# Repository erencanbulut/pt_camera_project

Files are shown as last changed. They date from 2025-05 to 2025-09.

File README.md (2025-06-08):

# PT Camera Project

The project aims to provide researchers with a low-cost, open-source pan-tilt (PT) camera system for use in various robotic applications, such as autonomous unmanned aerial vehicle (UAV) landings on unmanned surface vehicles (USVs).

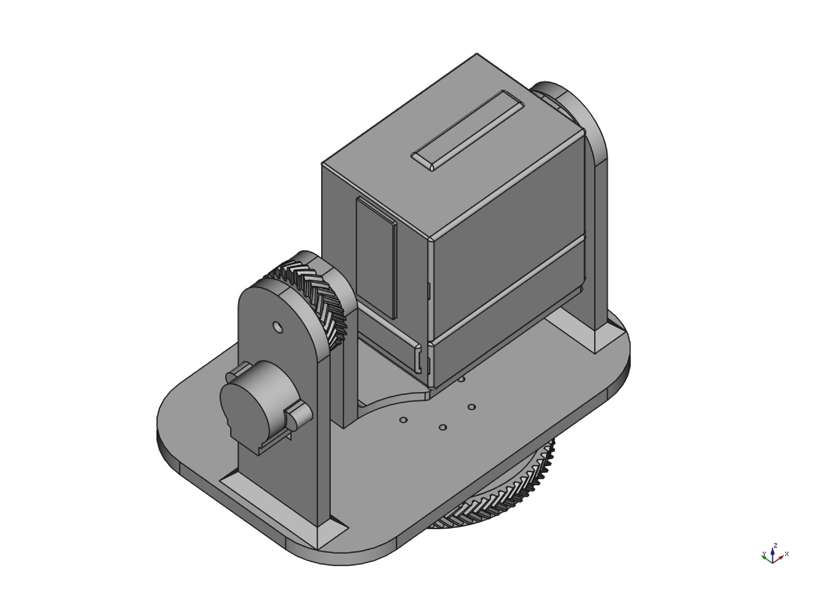
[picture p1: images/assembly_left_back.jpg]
PT Camera Assembly


# BoM
| Item Nr. | Product | Price (€) | Pieces | Link |
|---|---|---|---|---|
| 1 | Raspberry Pi 4 Model B 4 GB RAM | 48.99 | 1 | [Link](https://mou.sr/43gMQWg) |
| 2 | Raspberry Pi 16 MM Lens | 59.00 | 1 | [Link](https://buyzero.de/en/products/16mm-teleobjektiv-fur-hq-kamera-16mm-telephoto-lens-for-hq-camera) |
| 3 | Raspberry Pi 12 MP HQ Camera | 52.00 | 1 | [Link](https://www.digikey.de/short/p40hw30b) |
| 4 | Micro-SDHC 32 GB, 120 MB/s | 5.70 | 1 | [Link](https://www.berrybase.de/sandisk-ultra-microsdhc-a1-120mb-s-class-10-speicherkarte-adapter-32gb) |
| 5 | RB-Moto2 with 28byj-48 Stepper Motors | 12.52 | 3 | [Link](https://www.reichelt.com/de/en/shop/product/raspberry_pi_-_motor_control_incl_stepper_motors_uln2803apg-176628) |
| 6 | Intenso 7313535 Powerbank 10,000 mAh | 14.49 | 1 | [Link](https://amzn.eu/d/eHD4hbB) |
| 7 | Prusament PETG Filament (1 kg) | 29.99 | 1 | [Link](https://www.prusa3d.com/de/produkt/prusament-petg-carmine-red-transparent-1kg/) |
| 8 | Charge Cable (C to C) | 13.84 | 1 | [Link](https://de.rs-online.com/web/p/usb-kabel/2566994?gb=bb) |
| 9 | SKF 623-2Z Deep Groove Ball Bearing  | 4.82 | 2 | [Link](https://motionparts.de/products/623-2z-skf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) |
| 10 | M3 Cylinder Screw | 3.50 | 25 | [Link](https://rc-schrauben.de/Zylinderkopfschraube-DIN-912-M3-x-12-Edelstahl-A2) |
| 11 | M3 Hex Nuts | 0.43 | 25 | [Link](https://de.farnell.com/en-DE/tr-fastenings/m3-hfst-z100/nut-full-steel-bzp-m3-pk100/dp/1419447) |
| 12 | M3 Washer | 0.43 | 25 | [Link](https://de.farnell.com/en-DE/duratool/wash3/washer-steel-m3-pk100/dp/1377496) |
| 13 | M2 Cylinder Screws | 1.60 | 8 | [Link](https://rc-schrauben.de/Zylinderkopfschraube-DIN-912-M2-x-8-Stahl-129) |
| 14 | M2 Hex Nuts | 1.08 | 4 | [Link](https://rc-schrauben.de/Hexagon-Nut-DIN-934-M2-Stainless-steel) |
| | **Total Price** | **248.11**| | |

# Test and Performance Analyses

This part summarizes the experimental results and performance analyses.

---

## Pan and Tilt Performance

### Maximum Angular Speed

| Axis | Theoretical Speed | Measured Avg. Speed | Notes |
|---|---|---|---|
| Pan  | 31.39°/s | ~28.83°/s | Small loss (~8%) |
| Tilt | 48.83°/s | ~38.69°/s | Greater loss (~20%) |

- **Cause**: Mechanical design and weight.
- **Solution**: Higher torque motors, lighter construction, step timing optimization.

### Maximum Angular Range

| Axis | Max Angle (Up/Down) |
|---|---|
| Pan  | ±360° |
| Tilt | -95° to +30° |

- **Limitation**: Weight and cable strain.

### Combined Motion Execution Time

- **Expected**: 6.34 s
- **Measured**: 7.78 s (~22.7% longer)
- **Reason**: Acceleration delay and stepper lag during combined pan/tilt motion

---

## Object Detection – Free-Fall (Vertical)

| Distance | Detection Rate |
|---|---|
| 0.5 m | 17.64% |
| 1 m | 23.74% |
| 2 m | 48.61% |

- **Test**: HSV-based tracking of a fast-dropping yellow ball.
- **Simulation**: UAV speed during descent (5 m/s).
- **Insight**: Detection improves with distance due to better motion visibility.
- **Needs**:
  - Faster frame rate
  - Reduced exposure time
  - Predictive tracking (Kalman)
  - Real-time lightweight AI models

---

## Object Detection – Oscillation (Lateral)

| Distance | Detection Rate |
|---|---|
| 0.5 m | 25.05% |
| 1 m | 59.05% |
| 2 m | 96.41% |

- **Test**: HSV-based tracking of a laterally oscillating yellow ball.
- **Simulation**: UAV lateral drift (300°/s).
- **Finding**: Excellent performance for lateral motion at long range (2 m).

---

## Latency Analysis

- **Mean latency**: ~93.75 ms
- **Range**: 83.3 – 104.2 ms
- **Impact**: 
  - Camera preview latency measured using 240 fps slow-motion recording.
  - Frame difference used to calculate latency: Latency (ms) = (Δframes / 240) x 1000

**Conclusion**: Sufficient for real-time UAV tracking (<150 ms acceptable limit)

---

## Power Consumption

- 10,000 mAh battery yields **8+ hours** runtime during full tracking operation.
- ~5× better energy efficiency than commercial PTZ systems.
- Modular design allows for easy battery replacement or upgrades.

---

## Maritime Suitability (Sea State)

| Sea State | Status |
|---|---|
| SS 0–3 | Stable tracking |
| SS 4 | Reduced performance |
| SS 5+ | Not suitable |

---

## Commercial Comparison

### Advantages
- Modular and open-source
- Low-cost and long battery life
- Reliable object tracking (esp. lateral)
- Weather-resistant housing

### Limitations
- Slower tracking speeds
- Higher weight → suited for static or vehicle-mounted use

---

## Recommended Improvements

- Upgrade to stronger, faster stepper motors
- Redesign cable routing for better tilt range
- Optimize mechanical parts for weight reduction
- Use Jetson Nano/Xavier for real-time AI-based tracking
- Add stereo vision for 3D detection and UAV depth estimation
- Field test in maritime environments

---

📁 GitHub Repository: [erencanbulut/pt_camera_project](https://github.com/erencanbulut/pt_camera_project)

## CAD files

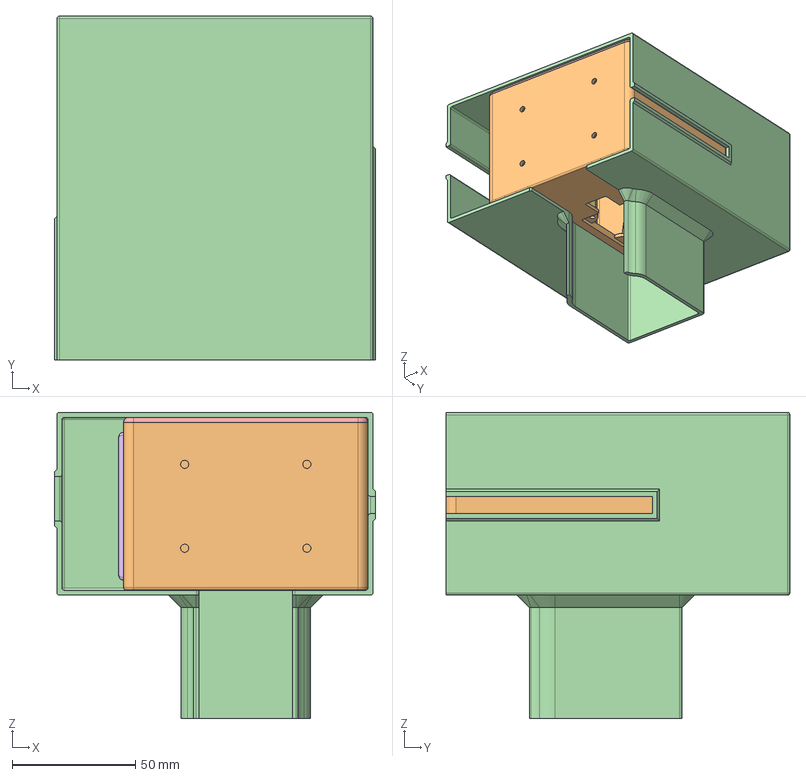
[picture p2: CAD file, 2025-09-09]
step_files/rpi_hq_cam_housing_v13.step
130.1 x 139.3 x 124.1 mm
FrontLid
CameraHousing
TopPortsLid
Case
BatterySlotLid
BatteryPortsLid
RPiPortsLid

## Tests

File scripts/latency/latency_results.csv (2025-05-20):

Real Frame | Preview Frame | ΔFrames | Latency (ms)
frame_6.png | frame_28.png | 22 | 91.67
frame_11.png | frame_32.png | 21 | 87.5
frame_15.png | frame_38.png | 23 | 95.83
frame_26.png | frame_46.png | 20 | 83.33
frame_29.png | frame_51.png | 22 | 91.67
frame_39.png | frame_60.png | 21 | 87.5
frame_46.png | frame_68.png | 22 | 91.67
frame_53.png | frame_75.png | 22 | 91.67
frame_60.png | frame_85.png | 25 | 104.17
frame_68.png | frame_90.png | 22 | 91.67
frame_76.png | frame_97.png | 21 | 87.5
frame_81.png | frame_106.png | 25 | 104.17
frame_90.png | frame_111.png | 21 | 87.5
frame_97.png | frame_119.png | 22 | 91.67
frame_104.png | frame_128.png | 24 | 100.0
frame_110.png | frame_133.png | 23 | 95.83
frame_119.png | frame_142.png | 23 | 95.83
frame_124.png | frame_149.png | 25 | 104.17
frame_133.png | frame_156.png | 23 | 95.83
frame_140.png | frame_161.png | 21 | 87.5
frame_145.png | frame_170.png | 25 | 104.17
frame_153.png | frame_174.png | 21 | 87.5
frame_160.png | frame_182.png | 22 | 91.67
frame_167.png | frame_190.png | 23 | 95.83
frame_174.png | frame_198.png | 24 | 100.0
frame_181.png | frame_202.png | 21 | 87.5
frame_188.png | frame_212.png | 24 | 100.0
frame_196.png | frame_216.png | 20 | 83.33
frame_202.png | frame_227.png | 25 | 104.17
frame_216.png | frame_238.png | 22 | 91.67

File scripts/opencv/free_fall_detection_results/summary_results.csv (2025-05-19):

Distance | Total Frames | Detected Frames | Detection Rate (%)
0.5 | 19 | 3 | 15.79
0.5 | 19 | 3 | 15.79
0.5 | 20 | 3 | 15.0
0.5 | 19 | 4 | 21.05
0.5 | 19 | 3 | 15.79
0.5 | 18 | 3 | 16.67
0.5 | 18 | 5 | 27.78
0.5 | 15 | 2 | 13.33
0.5 | 18 | 2 | 11.11
0.5 | 13 | 3 | 23.08
1 | 17 | 4 | 23.53
1 | 16 | 3 | 18.75
1 | 16 | 5 | 31.25
1 | 12 | 3 | 25.0
1 | 17 | 4 | 23.53
1 | 15 | 3 | 20.0
1 | 18 | 4 | 22.22
1 | 17 | 4 | 23.53
1 | 17 | 4 | 23.53
1 | 17 | 4 | 23.53
2 | 17 | 8 | 47.06
2 | 17 | 8 | 47.06
2 | 17 | 8 | 47.06
2 | 18 | 9 | 50.0
2 | 13 | 6 | 46.15
2 | 17 | 8 | 47.06
2 | 16 | 8 | 50.0
2 | 15 | 7 | 46.67
2 | 18 | 9 | 50.0
2 | 16 | 8 | 50.0

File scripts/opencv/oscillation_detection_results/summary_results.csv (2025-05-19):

Distance (m) | Total Frames | Detected Frames | Detection Rate (%)
0.5 | 637 | 150 | 23.55
0.5 | 637 | 150 | 23.55
0.5 | 640 | 163 | 25.47
0.5 | 639 | 180 | 28.17
0.5 | 639 | 159 | 24.88
0.5 | 647 | 160 | 24.73
0.5 | 638 | 153 | 23.98
0.5 | 523 | 123 | 23.52
0.5 | 636 | 159 | 25.0
0.5 | 527 | 135 | 25.62
1 | 637 | 393 | 61.7
1 | 642 | 382 | 59.5
1 | 635 | 320 | 50.39
1 | 627 | 425 | 67.78
1 | 640 | 374 | 58.44
1 | 536 | 337 | 62.87
1 | 633 | 368 | 58.14
1 | 632 | 375 | 59.34
1 | 632 | 321 | 50.79
1 | 629 | 387 | 61.53
2 | 591 | 576 | 97.46
2 | 607 | 587 | 96.71
2 | 601 | 581 | 96.67
2 | 608 | 586 | 96.38
2 | 608 | 591 | 97.2
2 | 603 | 575 | 95.36
2 | 611 | 594 | 97.22
2 | 610 | 589 | 96.56
2 | 607 | 580 | 95.55
2 | 605 | 581 | 96.03

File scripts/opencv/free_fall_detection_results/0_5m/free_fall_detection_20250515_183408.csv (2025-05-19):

Timestamp | Detected | X | Y | Radius (px)
0.042 | 0 | -1 | -1 | -1
0.392 | 0 | -1 | -1 | -1
0.452 | 0 | -1 | -1 | -1
0.5 | 0 | -1 | -1 | -1
0.547 | 0 | -1 | -1 | -1
0.591 | 0 | -1 | -1 | -1
0.641 | 0 | -1 | -1 | -1
0.683 | 0 | -1 | -1 | -1
0.717 | 0 | -1 | -1 | -1
0.746 | 0 | -1 | -1 | -1
0.777 | 0 | -1 | -1 | -1
0.81 | 0 | -1 | -1 | -1
0.838 | 0 | -1 | -1 | -1
0.867 | 0 | -1 | -1 | -1
0.898 | 0 | -1 | -1 | -1
0.93 | 1 | 531 | 66 | 79
0.959 | 1 | 505 | 237 | 216
0.989 | 1 | 522 | 435 | 58
1.023 | 0 | -1 | -1 | -1

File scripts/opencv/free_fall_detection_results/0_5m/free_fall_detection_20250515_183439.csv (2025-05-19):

Timestamp | Detected | X | Y | Radius (px)
0.042 | 0 | -1 | -1 | -1
0.392 | 0 | -1 | -1 | -1
0.441 | 0 | -1 | -1 | -1
0.495 | 0 | -1 | -1 | -1
0.541 | 0 | -1 | -1 | -1
0.579 | 0 | -1 | -1 | -1
0.625 | 0 | -1 | -1 | -1
0.661 | 0 | -1 | -1 | -1
0.694 | 0 | -1 | -1 | -1
0.724 | 0 | -1 | -1 | -1
0.757 | 0 | -1 | -1 | -1
0.787 | 0 | -1 | -1 | -1
0.815 | 0 | -1 | -1 | -1
0.842 | 1 | 462 | 49 | 76
0.876 | 1 | 462 | 226 | 228
0.909 | 1 | 486 | 424 | 56
0.937 | 0 | -1 | -1 | -1
0.968 | 0 | -1 | -1 | -1
1.0 | 0 | -1 | -1 | -1

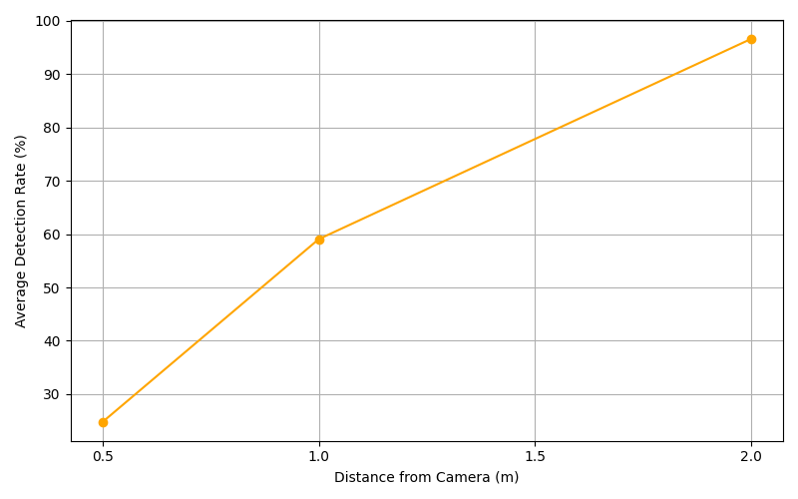
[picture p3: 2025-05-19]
scripts/opencv/oscillation_detection_results/detection_rate_vs_distance_oscillation.png

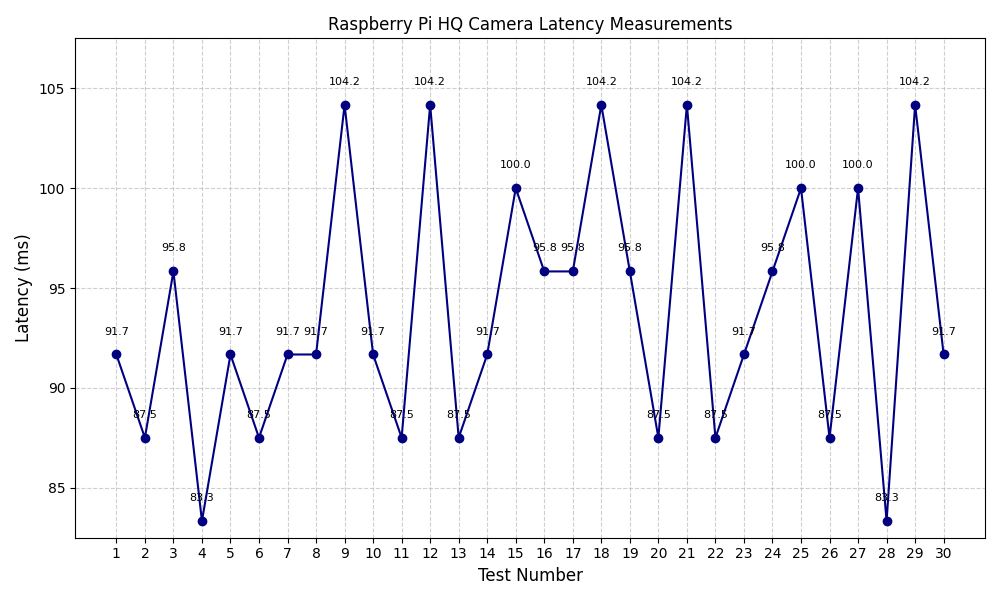
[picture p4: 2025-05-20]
scripts/latency/Raspberry_Pi_HQ_Camera_Latency_Measurements.png

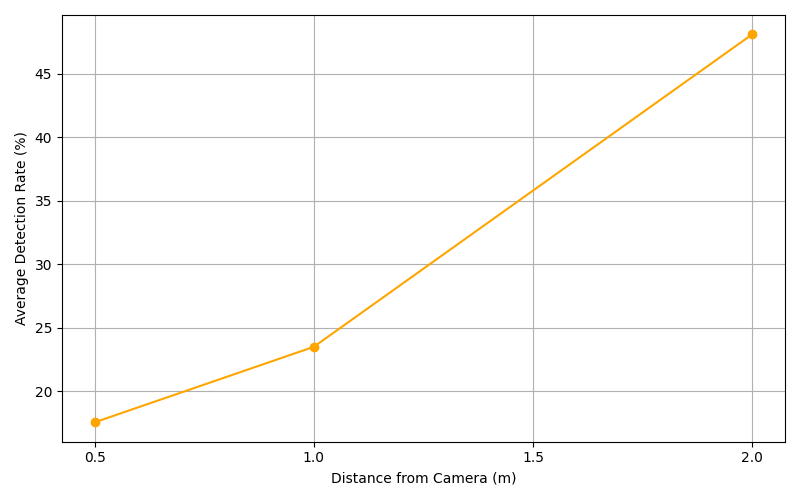
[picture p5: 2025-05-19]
scripts/opencv/free_fall_detection_results/detection_rate_vs_distance_free-fall.png

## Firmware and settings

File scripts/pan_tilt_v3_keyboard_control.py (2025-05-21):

# -*- coding: utf-8 -*-
"""
Pan and Tilt Control with Keyboard Arrow Keys
Use arrow keys to move pan and tilt motors by fixed 1° increments (5 steps for pan, 3 steps for tilt).
Press 'q' to exit.
"""
import sys
import termios
import tty
from gpiozero import OutputDevice
import time

# Define the pins as OutputDevice instances
# Pan motor pins
coil_A_1_pin = OutputDevice(24)  # pink
coil_A_2_pin = OutputDevice(4)   # orange
coil_B_1_pin = OutputDevice(23)  # blue
coil_B_2_pin = OutputDevice(25)  # yellow

# Tilt motor pins
coil2_A_1_pin = OutputDevice(18)  # pink
coil2_A_2_pin = OutputDevice(22)  # orange
coil2_B_1_pin = OutputDevice(17)  # blue
coil2_B_2_pin = OutputDevice(27)  # yellow

# Step sequence for 4-wire stepper
StepCount = 8
Seq = [
    [0, 1, 0, 0],
    [0, 1, 0, 1],
    [0, 0, 0, 1],
    [1, 0, 0, 1],
    [1, 0, 0, 0],
    [1, 0, 1, 0],
    [0, 0, 1, 0],
    [0, 1, 1, 0]
]

# Movement parameters
PAN_STEPS = 5    # steps for ~1° pan
TILT_STEPS = 3    # steps for ~1° tilt
DELAY_PAN = 0.7 / 1000.0   # seconds
DELAY_TILT = 0.9 / 1000.0  # seconds

# Pan motor control functions
def setStepPan(w1, w2, w3, w4):
    coil_A_1_pin.value = w1
    coil_A_2_pin.value = w2
    coil_B_1_pin.value = w3
    coil_B_2_pin.value = w4


def forwardPan(delay, steps):
    for _ in range(steps):
        for j in range(StepCount):
            setStepPan(*Seq[j])
            time.sleep(delay)


def backwardPan(delay, steps):
    for _ in range(steps):
        for j in reversed(range(StepCount)):
            setStepPan(*Seq[j])
            time.sleep(delay)

# Tilt motor control functions
def setStepTilt(w1, w2, w3, w4):
    coil2_A_1_pin.value = w1
    coil2_A_2_pin.value = w2
    coil2_B_1_pin.value = w3
    coil2_B_2_pin.value = w4


def upwardTilt(delay, steps):
    for _ in range(steps):
        for j in reversed(range(StepCount)):
            setStepTilt(*Seq[j])
            time.sleep(delay)


def downwardTilt(delay, steps):
    for _ in range(steps):
        for j in range(StepCount):
            setStepTilt(*Seq[j])
            time.sleep(delay)

# Get a single character (including arrow keys) from stdin

def getKey():
    fd = sys.stdin.fileno()
    old_settings = termios.tcgetattr(fd)
    try:
        tty.setraw(fd)
        ch1 = sys.stdin.read(1)
        if ch1 == '\x1b':  # ANSI escape sequence
            ch2 = sys.stdin.read(1)
            ch3 = sys.stdin.read(1)
            return ch1 + ch2 + ch3
        return ch1
    finally:
        termios.tcsetattr(fd, termios.TCSADRAIN, old_settings)

# Main control loop
if __name__ == '__main__':
    print("Use arrow keys to pan/tilt (1° per press). Press 'q' to quit.")
    try:
        while True:
            key = getKey()
            if key == 'q':
                print("Exiting.")
                break
            elif key == '\x1b[C':  # Right arrow
                print("Pan right 1°")
                forwardPan(DELAY_PAN, PAN_STEPS)
            elif key == '\x1b[D':  # Left arrow
                print("Pan left 1°")
                backwardPan(DELAY_PAN, PAN_STEPS)
            elif key == '\x1b[A':  # Up arrow
                print("Tilt up 1°")
                upwardTilt(DELAY_TILT, TILT_STEPS)
            elif key == '\x1b[B':  # Down arrow
                print("Tilt down 1°")
                downwardTilt(DELAY_TILT, TILT_STEPS)
    except KeyboardInterrupt:
        print("Interrupted by user. Exiting.")
    finally:
        # Reset all coils off
        setStepPan(0,0,0,0)
        setStepTilt(0,0,0,0)

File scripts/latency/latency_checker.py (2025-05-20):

import os
import cv2
import glob
import re
import csv

# === CONFIG ===
frames_folder = "/home/workspace/scripts/latency"  # Replace with your folder name
fps = 240  # Recording FPS

# === NUMERIC SORT FUNCTION ===
def extract_frame_number(path):
    match = re.search(r'frame_(\d+)\.png', os.path.basename(path))
    return int(match.group(1)) if match else -1

frame_paths = sorted(
    glob.glob(os.path.join(frames_folder, "frame_*.png")),
    key=extract_frame_number
)

if not frame_paths:
    print("No frames found. Check folder path.")
    exit()

# === INSTRUCTIONS ===
print("\n INSTRUCTIONS:")
print("→ : Next frame")
print("← : Previous frame")
print("'r': Mark REAL stopwatch frame")
print("'p': Mark Pi PREVIEW frame")
print("'s': Save current latency pair")
print("'q': Quit\n")

index = 0
real_frame_idx = None
preview_frame_idx = None
results = []

# === MAIN LOOP ===
while True:
    frame = cv2.imread(frame_paths[index])
    display = frame.copy()

    fname = os.path.basename(frame_paths[index])
    cv2.putText(display, f"Frame: {fname}", (20, 30),
                cv2.FONT_HERSHEY_SIMPLEX, 0.8, (0, 255, 255), 2)

    if real_frame_idx == index:
        cv2.putText(display, "Marked: REAL", (20, 60),
                    cv2.FONT_HERSHEY_SIMPLEX, 0.8, (255, 0, 0), 2)
    if preview_frame_idx == index:
        cv2.putText(display, "Marked: PREVIEW", (20, 90),
                    cv2.FONT_HERSHEY_SIMPLEX, 0.8, (0, 255, 0), 2)

    cv2.imshow("Latency Measurement", display)
    key = cv2.waitKey(0)

    if key == ord('q'):
        break
    elif key == 83:  # →
        index = min(index + 1, len(frame_paths) - 1)
    elif key == 81:  # ←
        index = max(index - 1, 0)
    elif key == ord('r'):
        real_frame_idx = index
        print(f"Marked REAL at {os.path.basename(frame_paths[index])}")
    elif key == ord('p'):
        preview_frame_idx = index
        print(f"Marked PREVIEW at {os.path.basename(frame_paths[index])}")
    elif key == ord('s'):
        if real_frame_idx is not None and preview_frame_idx is not None:
            delta = preview_frame_idx - real_frame_idx
            latency_ms = (delta / fps) * 1000
            result = {
                "Real Frame": os.path.basename(frame_paths[real_frame_idx]),
                "Preview Frame": os.path.basename(frame_paths[preview_frame_idx]),
                "ΔFrames": delta,
                "Latency (ms)": round(latency_ms, 2)
            }
            results.append(result)
            print(f"Saved: {result}")
            real_frame_idx = None
            preview_frame_idx = None
        else:
            print("Please mark both REAL and PREVIEW frames before saving.")

cv2.destroyAllWindows()

# === WRITE TO CSV ===
if results:
    with open("latency_results.csv", "w", newline="") as f:
        writer = csv.DictWriter(f, fieldnames=results[0].keys())
        writer.writeheader()
        writer.writerows(results)
    print(f"\n {len(results)} latency entries saved to 'latency_results.csv'")
else:
    print("\n No latency entries to save.")

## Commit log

2025-05-19 opencv & step_files & pt_codes added
    [detection_data_0.5m_20250516_152841.csv, detection_data_0.5m_20250516_152952.csv, detection_data_0.5m_20250516_153030.csv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]
2025-05-20 latecy folder update
    [detection_data_0.5m_20250516_152841.csv, detection_data_0.5m_20250516_152952.csv, detection_data_0.5m_20250516_153030.csv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]
2025-05-27 BoM added to the README.md
2025-06-08 assembly_left_back.jpg added
2025-09-09 rpi_hq_cam_housing_v13.step upgrade
    [hq_cam_housing_rpi4_v12_assembly.step, rpi_hq_cam_housing_v13.step]
